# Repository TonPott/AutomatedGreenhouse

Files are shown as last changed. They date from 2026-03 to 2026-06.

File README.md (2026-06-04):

# Grow Controller (Arduino Nano 33 IoT)

This repository contains the firmware and project documentation for a grow controller based on an **Arduino Nano 33 IoT**.

The controller manages and monitors:

- temperature and humidity via an **SHT3x**
- a **12V 3-pin fan** with tachometer evaluation
- a **dimmable grow light** via AD5263 dimmer + relay
- a **capacitive soil moisture sensor**
- a **CQRTSL25911 / TSL25911 cabinet light sensor**
- a **DS3231 RTC with AT24C32 EEPROM**
- **Home Assistant** integration via **MQTT** using **ArduinoHA**

The system should work with Home Assistant and also continue operating locally and autonomously if the connection is lost.

## Project Structure

```text
.
|-- AGENTS.md
|-- README.md
|-- SPEC.md
|-- MODULES.md
|-- HARDWARE.md
|-- ROADMAP.md
|-- DECISIONS.md
|-- libraries.txt
|-- arduino-cli.yaml
|-- sketches/
|   `-- Smaeenhouse/
|       |-- Smaeenhouse.ino
|       |-- sketch.yaml
|       |-- Credentials.example.h
|       `-- *.h / *.cpp
|-- hardware-tests/
|   |-- README.md
|   `-- <test-sketch>/
|-- scripts/
|   |-- setup-arduino.*
|   |-- check-arduino.*
|   |-- cleanup-worktree.*
|   `-- cleanup-arduino-toolchain.*
`-- .github/workflows/arduino-compile.yml
```

The project remains Arduino-IDE-compatible. Open `sketches/Smaeenhouse/Smaeenhouse.ino` in the Arduino IDE.

## Project Overview For New Users

Recommended reading order:

1. Review the **schematic in the project folder** (`FullArduinoHouse.fzz`)
2. Read `SPEC.md` for functional requirements
3. Read `HARDWARE.md` for board, wiring, signal levels, and safety notes
4. Read `MODULES.md` for technical structure
5. Read `docs/entity-model.md` for Home Assistant entities
6. Read `ROADMAP.md` for open validation and follow-up work
7. Read `DECISIONS.md` for design rationale and major decisions
8. Read `libraries.txt` for required Arduino libraries

The schematic in the project folder is the primary wiring reference. Text documentation adds explanatory context for review and maintenance.

## Setup

Arduino CLI setup is a one-time preparation per local machine. The setup scripts may update Arduino indexes, install the board core, and prepare libraries.

Windows:

```powershell
.\scripts\setup-arduino.ps1
```

Linux / Codex Cloud / GitHub Actions:

```bash
./scripts/setup-arduino.sh
```

By default, all worktrees of this repository use a shared Arduino home:

- Windows: `%LOCALAPPDATA%\ArduinoCodex\<repo-name>\arduino-cli`
- Linux/macOS: `$HOME/.cache/arduino-codex/<repo-name>/arduino-cli`

Set `ARDUINO_PROJECT_HOME` to use a different toolchain location.

## Compile Check

Compile checks do not install anything. They generate an ignored local Arduino CLI configuration under `.local/arduino-cli.yaml`, use the shared toolchain, and write build output to `.build/`.

Windows:

```powershell
.\scripts\check-arduino.ps1
```

Linux / Codex Cloud / GitHub Actions:

```bash
./scripts/check-arduino.sh
```

The default sketch is `sketches/Smaeenhouse`. The default profile is `nano33iot`.

Hardware test example:

```powershell
$env:SKETCH = "hardware-tests/AD5263Test"
.\scripts\check-arduino.ps1
```

```bash
SKETCH=hardware-tests/AD5263Test ./scripts/check-arduino.sh
```

If the compile check reports that the Arduino toolchain is not prepared, run the matching setup script once and retry.

## Version Policy

This project pins core and library versions deliberately because the production firmware depends on specific board, networking, RTC, sensor, persistence, and Home Assistant APIs.

Keep these files in sync whenever dependencies change:

- `libraries.txt`
- `sketches/Smaeenhouse/sketch.yaml`
- `scripts/setup-arduino.ps1`
- `scripts/setup-arduino.sh`

Normal compile checks must not install missing dependencies. Run setup first when a pinned core or library version changes, then run the compile check.

## Credentials

Create a local `sketches/Smaeenhouse/Credentials.h` file based on `sketches/Smaeenhouse/Credentials.example.h`.

**Important:** `Credentials.h` must not be committed to the repository. The check scripts temporarily copy `Credentials.example.h` only when no real credentials file exists, and remove that temporary file after compilation.

For hardware-test compile checks that include credential-dependent modules, the scripts may temporarily copy the production example credentials into the selected test sketch folder. Real hardware uploads should use real local credentials, never committed credentials.

## Cleanup

Worktree-local generated files can be removed with:

```powershell
.\scripts\cleanup-worktree.ps1
```

```bash
./scripts/cleanup-worktree.sh
```

These scripts remove `.build/`, `.arduino-cache/`, `.local/`, and `.arduino/` in the current worktree. They do not delete the shared Arduino toolchain.

The shared toolchain is intentionally long-lived. Manual project-end cleanup uses separate scripts that require confirmation:

```powershell
.\scripts\cleanup-arduino-toolchain.ps1
```

```bash
./scripts/cleanup-arduino-toolchain.sh
```

## Important Hardware Notes

- The RTC module provides a **DS3231** RTC and **AT24C32** EEPROM. The firmware uses RTClib for the RTC and JC_EEPROM for the external EEPROM.
- The grow light is dimmed through an `AD5263BRUZ50` as a digitally adjustable resistance between `Dim+` and `Dim-`; the relay remains responsible for hard switching the mains supply.
- The fan tach signal is converted to 3.3 V logic through a **2N3904 transistor stage**. See `HARDWARE.md` for the exact signal-conditioning notes.
- The **SQW/INT output** of the DS3231 is used for Arduino-internal light schedule alarms.
- The CQRTSL25911 light sensor is placed inside the cabinet and is initially measurement-only. Its INT line is wired for future use, but the firmware polls it over I2C.

## Measurement Data Privacy

Real sensor histories and HA exports from the cabinet or room are sensitive project data. Keep timestamped measurements, calibration datasets, and analysis exports in ignored local folders such as `measurements/`, `data/`, `exports/`, `ha-history/`, or `home-assistant-history/`; do not commit them to GitHub.

## Home Assistant

The MQTT/HA integration is based on the Arduino Home Assistant Integration by Dawid Chyrzynski:

https://github.com/dawidchyrzynski/arduino-home-assistant

Further details are documented in `docs/entity-model.md`.

## Codex Workflow

- Open the repository root in the Codex app, not the sketch folder.
- Keep changes small and reviewable.
- After code or build configuration changes, run `scripts/check-arduino`.
- After documentation-only changes, a diff review is sufficient.
- Do not commit generated build artifacts.
- Run hardware tests and uploads to real boards locally.

Recommended local Codex actions:

```text
Arduino Setup   -> .\scripts\setup-arduino.ps1
Arduino Compile -> .\scripts\check-arduino.ps1
```

Current open tasks and validation steps are tracked in `ROADMAP.md`. Important design decisions are recorded in `DECISIONS.md`.

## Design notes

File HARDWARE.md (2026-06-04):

# HARDWARE.md - Physical Build And Wiring Overview

## Purpose

Document the physical hardware target for this firmware.

Keep wiring, pin assignments, power domains, and signal-level assumptions here so firmware changes can be reviewed against the real build. The schematic in the project folder (`FullArduinoHouse.fzz`) is the primary wiring reference.

## Target Board

- Board: Arduino Nano 33 IoT
- FQBN: `arduino:samd:nano_33_iot`
- Logic voltage: 3.3 V
- Firmware sketch: `sketches/Smaeenhouse/Smaeenhouse.ino`

## Connected Hardware

- CQrobot CQRSHT31FA temperature and humidity sensor (Sensirion SHT31-DIS-F, I2C + alert pin)
- 3-pin 12 V PC fan
- WINGONEER Tiny DS3231 AT24C32 I2C module
  - DS3231 RTC
  - AT24C32 external EEPROM
  - SQW/INT output for RTC alarms
- DFRobot Capacitive Soil Moisture Sensor SEN0308
- ViparSpectra P1000 grow light
  - 230 V supply switched via 3.3 V relay module
  - dimming through variable resistance between `Dim+` and `Dim-`
- AD5263BRUZ50 on TSSOP-24 adapter as digitally controlled resistance
- CQrobot CQRTSL25911 illuminance sensor (TSL25911, I2C + prepared interrupt line)
- Home Assistant with MQTT

## Power Domains

- USB / logic power: Arduino Nano 33 IoT 3.3 V logic domain.
- External actuator power: 12 V fan supply and relay-switched grow-light mains supply.
- Common ground requirements: low-voltage control/sensor circuitry must share the required reference ground according to the schematic.
- Mains wiring is outside firmware safety guarantees and must be built, isolated, fused, and enclosed safely.

## Pin Map

| Pin | Direction | Function | Notes |
|---|---|---|---|
| `7` | Input interrupt | SHT alert | ISR only sets `shtAlertPending`; I2C evaluation happens in loop code. |
| `10` | Input interrupt | DS3231 SQW/INT | ISR only sets `rtcAlarmPending`; RTClib alarm evaluation happens in loop code. |
| `2` | Output | Fan switch | Controls the 12 V fan switch stage. |
| `A1` | Input interrupt | Fan tach | 2N3904-conditioned inverted tach signal. |
| `3` | Output | Light power relay | Hard power switching for the grow light. |
| `4` | Output | AD5263 `SHDN` | External 10 kOhm pull-down; no internal pull-up. |
| `A0` | Analog input | Soil moisture | SEN0308 analog signal. |
| `9` | Input | CQRTSL25911 INT | Reserved and wired for future light-sensor interrupt use; firmware v1 polls over I2C and does not attach an ISR. |
| `SDA/SCL` | I2C | SHT31, DS3231, AT24C32, AD5263, CQRTSL25911 | Use 3.3 V-compatible pull-ups. |

## I2C Devices

| Device | Role | Address / Notes |
|---|---|---|
| SHT31-DIS-F | Temperature/humidity measurement and alert status | Address according to sensor wiring. |
| DS3231 | RTC and light schedule alarms | SQW/INT connected to `PIN_RTC_ALARM`. |
| AT24C32 | External EEPROM for persistent configuration | Fixed project address `0x57`. |
| AD5263BRUZ50 | Grow-light dimmer resistance path | Fixed project address `0x2C` (`AD0 = GND`, `AD1 = GND`). |
| CQRTSL25911 / TSL25911 | Cabinet illuminance measurement | Fixed sensor address `0x29`; INT line is wired to `PIN_LIGHT_SENSOR_INT` for future use. |

No I2C access may happen in ISRs.

## Cabinet Light Sensor Placement

The CQRTSL25911 is placed inside the plant cabinet, where it measures the light that actually reaches the cabinet environment. Because the sensor is under the grow light when the lamp is on, it is not a reliable standalone room ambient-light sensor during lamp operation.

In the initial firmware integration, this sensor is measurement-only:

- cabinet illuminance and raw light channels are published to Home Assistant
- the light schedule, dimming jobs, and fallback behavior are not changed by the sensor
- the INT line is physically prepared, but no interrupt-driven light-sensor logic is used yet

## Light Dimmer Signal Conditioning

The grow light is dimmed through an `AD5263BRUZ50` as a digitally adjustable resistance between `Dim+` and `Dim-`.

Hardware assumptions:

- AD5263BRUZ50 in I2C mode (`DIS = 1`)
- pull-ups on SDA/SCL to 3.3 V
- `SHDN` on `PIN_LIGHT_DIM_SHDN` with external 10 kOhm pull-down
- no internal pull-up on `SHDN`
- analog channel wiring: `Dim+ -> W2 -> B2 -> A1 -> W1 -> Dim-`
- minimal effective resistance / approximately 0 Ohm = 0 %
- maximal effective resistance / approximately 100 kOhm = 100 %

Reference mapping:

- `0 %  => W2 = 0,   W1 = 255`
- `50 % => W2 = 0,   W1 = 0`
- `100 % => W2 = 255, W1 = 0`

The relay remains responsible for hard switching the 230 V supply.

## Fan Tach Signal Conditioning

The fan tach signal is converted to 3.3 V logic for the Nano 33 IoT through a **2N3904 transistor stage**:

- fan tach with 10 kOhm pull-up to 9 V
- tach through 47 kOhm to the base of a 2N3904
- 100 kOhm from base to GND
- emitter to GND
- collector to `PIN_FAN_TACH`
- 10 kOhm pull-up from collector to 3.3 V

The resulting signal is inverted; firmware must select the interrupt edge accordingly.

## Safety Notes

- Do not rely on firmware as the only safety layer for mains wiring.
- Relay wiring, mains isolation, strain relief, fuse protection, and enclosure design must be handled physically.
- Keep water, soil, condensation, and low-voltage electronics physically separated from mains wiring.
- The AD5263 dimmer path is not galvanically isolated by firmware.
- Hardware tests that actuate the relay or light require a safe physical setup.

## Open Hardware Validation Items

Track concrete validation work in `ROADMAP.md`; keep only hardware context here.

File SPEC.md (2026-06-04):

## Requirements List

## 1. Project Goal

The Arduino Nano 33 IoT controls a grow setup with:

- SHT3x temperature/humidity sensor
- 12V fan with tachometer signal
- dimmable grow light
- RTC_DS3231 + external AT24C32 EEPROM
- capacitive soil moisture sensor
- Home Assistant integration via MQTT

The system should cooperate with Home Assistant, but continue operating locally and autonomously if the connection is lost.

## 2. Hardware

### 2.1 Microcontroller
- Arduino Nano 33 IoT

### 2.2 Sensors And Actuators
- SHT3x via I²C with alert pin
- 3-pin 12V PC fan
- WINGONEER Tiny DS3231 AT24C32 I2C module
  - RTC via I²C with RTClib, type `RTC_DS3231`
  - external I²C EEPROM `AT24C32`
  - SQW/INT output for RTC alarms
- Grow Light:
  - dimming via a digitally adjustable resistance (AD5263) between `Dim+` and `Dim-`
  - hard shutoff via 3.3 V relay module
- DFRobot Capacitive Soil Moisture Sensor SEN0308
- WiFi + MQTT to Home Assistant

### 2.3 Hardware Documentation Requirement
The project documentation should also be understandable for users seeing the project for the first time.
The schematic in the project folder is the primary reference and should be explicitly mentioned in the text documents.

## 3. Pin Assignment

- SHT Alert: Pin 7
- RTC Alarm (SQW/INT): Pin 10
- Fan Switch: Pin 2
- Fan Tach: Pin A1
- Light Power Relay: Pin 3
- Light Dim SHDN: Pin 4
- Light Dimmer: I²C (SDA/SCL, AD5263 @ 0x2C)
- Soil Moisture: Pin A0

## 4. Temperature / Humidity / SHT3x
### 4.1 Measurement
The SHT3x periodically measures temperature and humidity.

These values should be:
- usable locally
- transmitted to Home Assistant

### 4.2 Thresholds
There are configurable thresholds:

- `TEMP_HIGH_SET`
- `TEMP_HIGH_CLEAR`
- `TEMP_LOW_SET`
- `TEMP_LOW_CLEAR`
- `HUM_HIGH_SET`
- `HUM_HIGH_CLEAR`
- `HUM_LOW_SET`
- `HUM_LOW_CLEAR`

These values should be:
- stored persistently in the external EEPROM
- written to the sensor at startup
- changeable from HA

### 4.3 Interrupt Logic
The SHT3x performs threshold monitoring.

When an alert occurs on pin 7, the status register is decoded. The relevant bits are especially:

- `alertTriggers[2]` = humidity tracking alert
- `alertTriggers[3]` = temperature tracking alert
- `alertTriggers[4]` = sensor reset detected

### 4.4 Reinitialization After Sensor Reset
If `alertTriggers[4]` is set, this should be used to reinitialize the sensor, or at least to write the configured thresholds to the sensor again.

### 4.5 Responsibility
- The FanController evaluates **no thresholds of its own**
- The SHT3x alert logic is authoritative

## 5. Fan

### 5.1 Automatic Mode
The fan is controlled based on the SHT3x alert logic:

- relevant alerts active → fan on
- clear state reached → fan off

### 5.2 Manual Mode
The fan should be manually switchable on and off in HA.

### 5.3 Auto Mode
There is an auto-mode switch for the fan:

- ON: sensor interrupts control the fan
- OFF: sensor interrupts are ignored, manual control remains active

### 5.4 RPM
The fan has 2 pulses per revolution.

RPM:
- measurement window 30 seconds
- only measure/publish if the fan should be running

### 5.5 Hardware Signal Conditioning For Tachometer
The documentation should include the used 2N3904 stage:

- tach line with 10 kΩ pull-up to 9 V
- tach through 47 kΩ to the base of a 2N3904
- 100 kΩ from base to GND
- emitter to GND
- collector to Arduino `PIN_FAN_TACH`
- 10 kΩ pull-up from collector to 3.3 V

The resulting signal is inverted.

## 6. Grow Light

### 6.1 Basic Structure
The light has two separate control paths:

- AD5263 dimmer path as variable resistance between `Dim+` and `Dim-`
- hard relay-off of the 230 V supply

### 6.2 Mandatory AD5263 Hardware

- Component: `AD5263BRUZ50`
- Mounted via TSSOP-24 adapter
- Supply:
  - `VDD = 12 V`
  - `VSS = GND`
  - `VL/VLOGIC = 3.3 V`
- Decoupling:
  - `100 nF` or `1 µF` between `VDD` and `VSS`
  - `100 nF` between `VL` and `GND`
- no galvanic isolation in the dimmer path

### 6.3 I²C Mode And Address

- `DIS = 1` for I²C mode
- `SDI/SDA` = SDA
- `CLK/SCL` = SCL
- `CS/AD0` and `RES/AD1` are the I²C address bits
- `AD0 = GND`
- `AD1 = GND`
- fixed 7-bit I²C address: `0x2C`
- pull-ups on the I²C lines to `3.3 V`

### 6.4 Mandatory Analog Channel Wiring

Only channel 1 and channel 2 of the AD5263 are used.

Mandatory signal path:

- `Dim+ -> W2 -> B2 -> A1 -> W1 -> Dim-`

### 6.5 Brightness Mapping To RDAC Values

The firmware continues to work logically with `0..100 %` brightness and maps internally to RDAC values.

Functional direction at the lamp dimmer input:

- low resistance between `Dim+` and `Dim-` = low brightness
- high resistance between `Dim+` and `Dim-` = high brightness
- minimal effective resistance / approximately `0 Ω` corresponds to `0 %`
- maximal effective resistance / approximately `100 kΩ` corresponds to `100 %`

Mandatory points:

- `0 % = W2 0, W1 255`
- `50 % = W2 0, W1 0`
- `100 % = W2 255, W1 0`

Mandatory intermediate logic:

- from `0 %` to `50 %`, channel 1 / `W1` changes first so the total resistance rises from the minimum value to the midpoint
- from `50 %` to `100 %`, channel 2 / `W2` changes afterwards so the total resistance rises from the midpoint to the maximum value
- on channel 1 the `A1-W1` stretch is used
- on channel 2 the `W2-B2` stretch is used

### 6.6 Resistance Limits

- target range at the light input: nominally approx. `0..100 kΩ`
- `0 Ω` is to be understood as minimal effective resistance or approximately `0 Ω`, because the AD5263 has residual resistance in rheostat mode
- practically approximated by the AD5263BRUZ50 with two channels in rheostat mode
- actually used lower/upper limits are set as project-internal firmware constants
- these dimmer limits are **not** configurable via HA

### 6.7 Two Control Worlds
A clean distinction must be maintained between:

- **Arduino Auto Schedule**
- **HA-controlled operation** (manual or by HA schedule)

The two must not control the light at the same time.

### 6.8 Light Modes

#### Mode A: Arduino Auto Mode ON
When `light_auto_mode = ON`:

- the internal Arduino schedule is active
- triggers from the HA schedule are ignored
- manual brightness adjustment is allowed, but only temporarily within the current time window
- at the next Arduino schedule event, the value is overwritten again
- the HA on/off switch for the light should have no effect in this mode or should be disabled

#### Mode B: Arduino Auto Mode OFF
When `light_auto_mode = OFF`:

- the Arduino schedule is inactive
- HA schedule triggers may control the light
- manual HA commands may control the light like a normal dimmable light
- on/off switch and brightness slider are active

### 6.9 Dimming Behavior
There is **no longer a single global fixed dimming ramp for all cases**.

Instead:

- Arduino schedule fades use the configured auto dim duration
- HA schedule commands use the duration provided by the command
- purely manual slider/switch operation in HA mode may make the light react immediately like a normal dimmable light

### 6.10 Hard Power Off
There is an additional separate HA switch/command for hard power off.

`light_hard_power_off` is an always-available safety override and may act in both Arduino Auto Mode and HA-controlled mode. It should not be hidden in the associated light/control cards based on light mode.

It should:

- switch only the relay immediately
- keep the internal dimmer state

### 6.11 SHDN Usage

- `SHDN` is actively used and pin 4 is used for it
- an external `10 kΩ` pull-down to GND is mandatory on `SHDN`
- because of this external pull-down, no internal pull-up is used for `SHDN`
- the AD5263 should remain in shutdown by default during reset/boot

### 6.12 Startup And Shutdown Sequence

Important:

- the AD5263 starts at midscale on power-on
- without a sequence, switching the relay on would otherwise cause an incorrect brightness start

Mandatory startup sequence:

1. AD5263 initially remains in `SHDN` during boot
2. Load configuration
3. Reconstruct target state
4. Set resistance value
5. Release `SHDN`
6. Only then close the relay

Mandatory shutdown sequence:

1. Open relay
2. Then put AD5263 into `SHDN`

### 6.13 Race Condition And Logic Rules For The Light
1. There is always exactly **one active light control source**:
   - Arduino Auto
   - or HA

2. When `light_auto_mode = ON`, HA schedule triggers are ignored.

3. When `light_auto_mode = OFF`, Arduino schedule events are ignored.

4. A new valid dimming request replaces any still-running old dimming request from the active control source.

5. When switching modes, a running dimming request is terminated; the new control source takes over only with its next valid command/event.

### 6.14 Fault Strategy For The Light Path

The AD5263 must be reachable before the relay is switched on and must provide a plausibly set target resistance. In case of AD5263 communication, write, or plausibility errors, the relay remains or is opened, the light stays off, and `light_fault` is set.

The technical retry/readback strategy belongs to the module description in `MODULES.md`.

Intended text values for `light_fault_reason`:

- `ad5263_not_found`
- `ad5263_write_failed`
- `ad5263_readback_mismatch`

## 7. Light Schedule Via DS3231 Alarms
### 7.1 Arduino-Internal Schedule
The Arduino stores internally:

- on / dim-on time
- off / dim-off time
- default dim duration

### 7.2 Time Format
Internal:
- minutes since midnight

### 7.3 RTC Alarm Usage
The Arduino-internal schedule should be implemented using the **two alarm registers of the DS3231**.

Requirements:
- the stored on/off times are written to the DS3231 alarm registers
- when an alarm occurs, an interrupt is triggered through the `SQW/INT` pin
- the ISR only sets a flag
- the main loop evaluates which alarm fired
- then the corresponding on/off dimming request is started

### 7.4 Library Requirement
It must be checked and used in the implementation that RTClib provides the required functions for `RTC_DS3231`, especially:

- `writeSqwPinMode(...)`
- `setAlarm1(...)`
- `setAlarm2(...)`
- `alarmFired(...)`
- `clearAlarm(...)`

### 7.5 Pull-Up Of The Alarm Line
Because `SQW/INT` is open drain, at least `INPUT_PULLUP` should be used on the Arduino side.
If the real line is unstable, an additional external pull-up to 3.3 V may be provided.

### 7.6 Distinction From HA Schedule
Section 7 applies only to the **Arduino-internal schedule**.

An additional HA schedule is separate from it and only effective when `light_auto_mode = OFF`.

## 8. Soil Moisture

### 8.1 Measurements
The following should be available:
- `sensor.soil_moisture_percent`: calculated soil moisture in %
- `sensor.soil_moisture_raw`: raw sensor value

### 8.2 Calibration Parameters
- `number.soil_air`
- `number.soil_water`
- `number.soil_depth_mm`

These values:
- are stored persistently
- are shown in HA
- can be changed in HA

`soil_air` and `soil_water` remain user-facing persistence values in the expected project range:

- min: 0
- max: 1000
- step: 1

Separately, the firmware sensor module may defensively clamp internal ADC raw values to the 12-bit safety range `0..4095`.

`soil_depth_mm` is an active correction parameter for percent calculation, not only an informational value.

### 8.3 Calibration
The calibration routine runs fully in HA.
The firmware does not manage a calibration assistant and does not contain an internal calibration state machine.

Therefore the firmware does not need to:
- know the calibration step
- pause measurements
- maintain an internal calibration status
- store individual intermediate steps

The firmware only needs to:
- periodically read the raw value
- periodically calculate the percent value from `soil_air`, `soil_water`, current raw value, and `soil_depth_mm`
- publish `sensor.soil_moisture_raw`
- publish `sensor.soil_moisture_percent` if the evaluation is valid
- provide the raw value on request
- accept final changes to `number.soil_air`, `number.soil_water`, and `number.soil_depth_mm`
- store changed persistence values in the external EEPROM

### 8.4 HA Operation
One firmware button is sufficient:

- `button.read_soil_raw_value`

Separate firmware buttons such as `capture_soil_air` or `capture_soil_water` should not be introduced. The existing generic button plus HA scripts/automations is sufficient and avoids unnecessary MQTT entities.

Intended HA-supported workflow:

1. Air step:
   - The user places the sensor dry in air.
   - HA calls `button.read_soil_raw_value`.
   - HA waits briefly until `sensor.soil_moisture_raw` is updated.
   - HA writes this value to `number.soil_air`.

2. Water step:
   - The user places the sensor in water at the reference depth of `120 mm`.
   - HA calls `button.read_soil_raw_value`.
   - HA waits briefly until `sensor.soil_moisture_raw` is updated.
   - HA writes this value to `number.soil_water`.

3. Depth step:
   - The user manually enters the actual insertion depth in the substrate in `number.soil_depth_mm`.
   - The firmware actively uses this value for the corrected percent calculation.

### 8.5 Depth Correction And Percent Calculation
The sensor response depends on how much active sensor area is actually inside the medium. Therefore the firmware uses a simple linear depth correction.

Definitions:

- `SOIL_REFERENCE_DEPTH_MM = 120`
- `soil_air`: raw value with sensor completely in air
- `soil_water`: raw value with sensor in water at 120 mm reference depth
- `soil_depth_mm`: actual insertion depth in the substrate

Concept:

```text
depth_factor = soil_depth_mm / SOIL_REFERENCE_DEPTH_MM
percent = (soil_air - raw) / ((soil_air - soil_water) * depth_factor) * 100
```

The air reference corresponds to `0 %`, and the water reference at `120 mm` corresponds to `100 %`. Valid results are constrained to `0..100 %`. The formula is a deliberate linear approximation; a measurement series exists, but the project currently accepts this model as sufficiently accurate.

### 8.6 Invalid Depth
Values below `20 mm` are considered invalid for soil moisture percent calculation.

Reason:

- The first physical sensor marking is at `20 mm`.
- Measurements below that are considered unreliable.

Constant meanings:

- `SOIL_DEPTH_MIN_MM = 0` is the technical/persistence lower bound and defensive lower bound for stored or injected values.
- `SOIL_MIN_VALID_DEPTH_MM = 20` is the first physical sensor marking, the minimum meaningful insertion depth, and the normal Home Assistant UI minimum.

Home Assistant normally exposes `number.soil_depth_mm` as `20..120 mm`. Values below `20 mm` are a defensive invalid state, not a normal user input path.

Firmware behavior:

- If `soil_depth_mm < 20`, `sensor.soil_moisture_percent` should be treated as invalid or unavailable.
- `sensor.soil_moisture_raw` may still be published.
- In this case, the firmware should not produce a misleading corrected percent value.

### 8.7 Measurement Interval
The soil moisture sensor should be read:
- every **10 seconds**
- and published to HA

It is useful to publish both:
- the raw value
- and the calculated percent value

## 9. RTC / Time / EEPROM

### 9.1 RTC Type
- `RTC_DS3231`

### 9.2 External EEPROM
Persistent configuration should not be stored in Arduino flash, but in the **AT24C32** on the RTC module.
Access to this EEPROM is performed through the **JC_EEPROM** library (which requires the **Streaming** library).
The I²C address of the AT24C32 EEPROM on the WINGONEER Tiny DS3231 AT24C32 I2C module has been verified in the real build and is fixed for this project.
It is 0x57.

Requirements:
- The firmware should use this known EEPROM I²C address directly.
- The EEPROM address should not be guessed, scanned, or searched automatically at runtime.
- The address is defined centrally in `Config.h` or a comparable configuration file.
- The persistence layer uses this fixed address for all read/write access through `JC_EEPROM`.
- The **JC_EEPROM** library requires the **Streaming** library as a dependency.

Reason:
- The EEPROM was accessed successfully with `JC_EEPROM` in the test build.
- This removes unnecessary auto-detection and keeps initialization simpler and more robust.

### 9.3 Usage
The RTC is the local time base for:
- Arduino light schedule
- autonomous operation when the connection is lost

The RTC alarms are the trigger source for the Arduino-internal light schedule.

### 9.4 Synchronization
The time should be synchronized:
- during boot
- at least 1× per day afterwards

Optionally additionally:
- manual sync via HA button

### 9.5 NTP
The firmware should actively synchronize via NTP and set the RTC from it.

Default NTP server:

- `pool.ntp.org`

NTP diagnostics should distinguish these failure classes in serial logs:

- DNS lookup failure
- UDP socket setup failure
- UDP packet send failure
- missing UDP response
- short UDP response
- invalid NTP timestamp

After an explicit UDP NTP failure, the firmware may use `WiFi.getTime()` as a secondary WiFiNINA module-time fallback/check. This fallback must not add HA entities.

UDP NTP sync may block briefly while waiting for a response during boot, manual sync, or daily resync. This is acceptable for now because it happens only during those sync attempts.

After successful time sync, the DS3231 alarm registers should be rewritten.

## 10. Cabinet Light Sensor

### 10.1 Sensor Type
The firmware includes a CQrobot CQRTSL25911 / TSL25911 light sensor on I2C address `0x29`.

The sensor is mounted inside the plant cabinet. It measures the cabinet light environment, not a clean room ambient-light value while the grow light is on.

### 10.2 Initial Firmware Role
The initial integration is measurement-only:

- read the sensor from normal loop code only
- publish cabinet illuminance and raw light-channel values to HA
- publish a separate `light_sensor_fault` state if repeated reads fail
- do not change the Arduino light schedule
- do not change HA dimming semantics
- do not change fallback or standalone light behavior

The sensor INT pin is wired to `PIN_LIGHT_SENSOR_INT` for future use. Firmware v1 does not attach an ISR and does not read I2C from interrupt context.

### 10.3 Future Lux-Hour Assistance
Future light assistance may use Home Assistant history to combine:

- cabinet illuminance from this sensor
- outside brightness from the existing exterior HA sensor
- current `grow_light` brightness
- time of day and schedule window

The intended future direction is a gradual lux-hour or light-sum compensation model. It should avoid end-of-day catch-up behavior where the lamp suddenly switches to full power because the daily total is low. Instead, HA should derive expected brightness by time of day and apply slow corrections through the existing HA dimming entities while `light_auto_mode = OFF`.

Standalone and fallback behavior remains conservative until a separate design explicitly defines safe local lux-based corrections. By default, connection loss continues to use the existing fallback behavior without lux-hour compensation.

### 10.4 Measurement Data Sensitivity
Real measurement histories are sensitive project data. Home Assistant exports, timestamped lux histories, calibration tables, and analysis datasets from the real cabinet or room must remain local and must not be committed to GitHub.

Documentation may describe algorithms and may include synthetic or anonymized examples, but not raw real-world measurement histories.

## 11. Home Assistant / MQTT

### 11.1 Library
Used library:
- Arduino Home Assistant Integration by Dawid Chyrzynski
- Reference: `https://github.com/dawidchyrzynski/arduino-home-assistant`

### 11.2 Device
The Arduino appears as one HA device.

### 11.3 HA Entities

#### Sensors
- `temperature`
- `humidity`
- `soil_moisture_percent`
- `soil_moisture_raw`
- `cabinet_illuminance_lux`
- `cabinet_light_full_spectrum_raw`
- `cabinet_light_infrared_raw`
- `cabinet_light_visible_raw`
- `fan_rpm`
- `light_fault`
- `fan_fault`
- `sht_fault`
- `rtc_fault`
- `eeprom_fault`
- `light_sensor_fault`
- `light_fault_reason`

Type mapping in HA:

- `binary_sensor.light_fault`
- `binary_sensor.fan_fault`
- `binary_sensor.sht_fault`
- `binary_sensor.rtc_fault`
- `binary_sensor.eeprom_fault`
- `binary_sensor.light_sensor_fault`
- `sensor.light_fault_reason` (text)

#### Switches
- `fan`
- `fan_auto_mode`
- `light_auto_mode`
- `light_hard_power_off`
- `light_fallback_to_auto`

#### Light
- `grow_light`
  - Brightness
  - ON/OFF
  - fully usable only when `light_auto_mode = OFF`

#### Number Entities
- temperature thresholds
- humidity thresholds
- Arduino light schedule times
- Arduino default dim duration
- `soil_air`
- `soil_water`
- `soil_depth_mm`
- `ha_dim_target_percent`
- `ha_dim_duration_minutes`

#### Buttons
- `sync time`
- `read_soil_raw_value`
- `start_ha_dim`

### 11.4 HA Dimming Request
For the HA schedule dimming job, operation is fixed as follows:

- `number.ha_dim_target_percent`
- `number.ha_dim_duration_minutes`
- `button.start_ha_dim`

Mandatory behavior:

- These three entities are used only for **HA schedule operation**
- They are effective only when `light_auto_mode = OFF`
- Pressing `button.start_ha_dim` starts a dimming request on the Arduino:
  - from the **current actual state**
  - to `ha_dim_target_percent`
  - within `ha_dim_duration_minutes`
- If `light_auto_mode = ON`, this dimming request is ignored

Persistence rule:

- The Number entities remain runtime/command parameters and are not durable configuration.
- If a HA dimming job is relevant after restart, its resumption is reconstructed through the `Light Resume State` (start/target/duration/start time on RTC/Epoch basis), not through `millis()`.

### 11.5 State Restoration
Separate sensors for actual light brightness or light mode are not required as long as:

- the state of the `light` entity is published correctly
- the `switch` states are published correctly
- after startup or MQTT reconnect, the current states are actively reported to HA again

## 12. Network / Connection Behavior

### 12.1 Connection
The device connects to:
- WiFi
- MQTT broker

### 12.2 Credentials
All credentials are in local `sketches/Smaeenhouse/Credentials.h`, at least:
- WiFi SSID
- WiFi password
- MQTT Host
- MQTT Port
- MQTT User
- MQTT password
- Device Name / ID / Prefix
- NTP server
- timezone / offset if needed

### 12.3 Availability / LWT
The device reports availability via MQTT and uses LWT.

### 12.4 Reconnect
On WiFi/MQTT outage, reconnect is automatic.

WiFi reconnect behavior must account for stale WiFiNINA connection state after sketch upload or module state transitions:

- force a WiFi disconnect before a reconnect sequence
- wait a short settle interval after disconnect
- use a bounded number of connection attempts
- use a connect timeout for each attempt
- keep diagnostics compact enough for serial troubleshooting

MQTT reconnect must be retried periodically while WiFi is connected. It must not depend only on a WiFi state transition.

### 12.5 Fallback After Connection Loss
If the connection is not restored for more than 10 minutes, a configurable behavior should apply for the light:

- turn light off
- or switch to internal Arduino Auto Mode

This behavior should be configurable via HA.

Other local functions such as sensors, RTC, EEPROM, and fan logic continue running.

## 13. Persistence

### 13.1 Storage Location
Used storage:

- `AT24C32` on the RTC module
- access through **JC_EEPROM**

### 13.2 Already Existing Persistent Configuration (Reuse)
Already existing and **not** to be created a second time:

- `lightAutoMode`
- `fanAutoMode`
- `lightOnTimeMinutes`
- `lightOffTimeMinutes`
- `defaultLightDimMinutes`
- `lightFallbackMode`
- additional sensor/soil/threshold values

### 13.3 Light Resume State (Add New)
In addition, a small resume state is required for target-state reconstruction, at least with:

- last effective brightness
- `hardPowerOffActive`
- flag whether a HA dimming job was active
- start brightness
- target brightness
- job duration
- job start time on RTC/Epoch basis

### 13.4 Time Base For Resumption

- `millis()` is not sufficient for restart resumption.
- Correct reconstruction after restart requires an RTC/Epoch-based time reference.

### 13.5 Write Behavior

- Write only when values actually changed.
- Design resume-state writes so unnecessary EEPROM load is avoided.

## 14. Architecture
### 14.1 Non-Blocking
- no long `delay()` calls
- control via `millis()`
- short I²C waits are allowed

### 14.2 Module Boundaries
- SHTa: sensor + alert evaluation
- FanController: fan switching + RPM measurement
- LightController: AD5263/relay + dimming requests
- LightSensor: CQRTSL25911/TSL25911 cabinet illuminance measurement
- ClockService: DS3231 + alarm management + NTP sync
- HAInterface: HA entities + commands
- NetworkManager: WiFi/MQTT + reconnect
- Persistence: external EEPROM

### 14.3 Fault States (Mandatory)
The following fault states are mandatory in the firmware documentation:

- `light_fault`
- `fan_fault`
- `sht_fault`
- `rtc_fault`
- `eeprom_fault`
- `light_sensor_fault`

In HA, these fault flags are published as `binary_sensor`.

Do not use:

- `sensor_fault`
- `system_fault`
- `last_fault_code`

Additional text state:

- `light_fault_reason`

In HA, `light_fault_reason` is published as a text `sensor`.

Intended contents of `light_fault_reason`:

- `ad5263_not_found`
- `ad5263_write_failed`
- `ad5263_readback_mismatch`

Mandatory behavior rules:

- AD5263 not reachable during boot: relay open, light off, set `light_fault`, `light_fault_reason = ad5263_not_found`.
- AD5263 error during operation: open relay, set `light_fault`, update `light_fault_reason`.
- The concrete retry/readback strategy is documented in `MODULES.md`.
- Fan fault: if the fan should effectively be on but no tach pulses are present after the grace period, set `fan_fault`.
- Do not claim strong hardware self-diagnostics for relay and soil moisture sensor, because there is no real feedback channel.

## 15. Reused Existing Code
### 15.1 SHTa
The following should especially be reused:

- `begin()`
- `startPeriodicMeasurement()`
- `blockingReadMeasurement()`
- `decodeStatusRegister()`
- `clearStatus()`
- `writeHighLimit()`
- `writeHighClear()`
- `writeLowLimit()`
- `writeLowClear()`
- `readLimit()`
- `limitPrinter()`
- `crc8()`
- `encodeAlertLimit()`

### 15.2 Alert Structure
- `alertTriggers[]` remains as status container

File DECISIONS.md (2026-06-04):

# Design Decisions

This file records important design, hardware, and architecture decisions for the project.
It explains why the current design looks the way it does.
It does not replace `README.md`, `SPEC.md`, `MODULES.md`, or `ROADMAP.md`.

## 2026-05 – Cabinet light sensor starts as measurement-only

Status: accepted

### Context

- The CQRTSL25911 sensor can only be placed inside the plant cabinet.
- When the grow light is on, the sensor measures the combined cabinet light environment and cannot independently evaluate room ambient light.
- A future light-sum design should also consider the outside brightness sensor that already exists in Home Assistant.

### Decision

- Integrate the CQRTSL25911 / TSL25911 first as a measurement-only firmware module.
- Publish cabinet illuminance and raw light channels to Home Assistant.
- Keep the existing Arduino schedule, HA dimming interface, and fallback behavior unchanged.
- Prepare the sensor INT line physically, but use polling in the initial firmware.
- Treat real measurement histories and HA exports as sensitive local data that must not be committed.

### Consequences

- The sensor can be logged in HA before any automatic control logic is designed.
- Future lux-hour compensation should be HA-first and should use existing HA dimming entities while `light_auto_mode = OFF`.
- Standalone/fallback lux-based behavior remains future work and must be designed explicitly before implementation.

### Affected Areas

- `SPEC.md`
- `MODULES.md`
- `HARDWARE.md`
- `docs/entity-model.md`
- `sketches/Smaeenhouse/LightSensor.*`
- `sketches/Smaeenhouse/HAInterface.*`

## 2026-05 – AD5263 replaces the old PWM/RC/PC817 dimmer concept

Status: accepted

### Context

- The old PWM/RC/PC817 dimmer path is no longer the target design.
- The lamp is controlled through a resistance between `Dim+` and `Dim-`.
- A digital potentiometer approach better matches the required control interface.

### Decision

- Use `AD5263BRUZ50` as the target dimmer component.
- Use two channels in series.
- Keep the hard relay path separate for 230 V power switching.
- Use SHDN for safe startup/shutdown behavior.

### Consequences

- The firmware uses AD5263/I²C control instead of PWM dimming.
- The old PWM/RC/PC817 path must not be reintroduced as a runtime option.
- Fault handling must protect against AD5263 communication/readback failures.
- Documentation and code must remain aligned on the AD5263 mapping.

### Affected Areas

- `SPEC.md`
- `MODULES.md`
- `sketches/Smaeenhouse/Config.h`
- `sketches/Smaeenhouse/LightController.*`
- `hardware-tests/AD5263Test/AD5263Test.ino`

## 2026-05 – Lamp dimmer direction is low resistance = low brightness, high resistance = high brightness

Status: accepted

### Context

- Real hardware testing showed that the previous mapping direction was inverted for the lamp.
- Swapping `Dim+` and `Dim-` is not expected to change a pure resistance input.

### Decision

- Treat minimal effective resistance / approximately `0 Ω` as `0 %`.
- Treat maximal effective resistance / approximately `100 kΩ` as `100 %`.
- Use the mapping:
  - `0 %  => W2 = 0,   W1 = 255`
  - `50 % => W2 = 0,   W1 = 0`
  - `100 % => W2 = 255, W1 = 0`

### Consequences

- Code, documentation, and AD5263 test sketch must use this mapping.
- Future changes to dimmer limits must preserve the direction unless new hardware evidence says otherwise.

### Affected Areas

- `SPEC.md`
- `MODULES.md`
- `sketches/Smaeenhouse/Config.h`
- `sketches/Smaeenhouse/LightController.cpp`
- `hardware-tests/AD5263Test/AD5263Test.ino`

## 2026-05 – Project documentation is maintained in English

Status: accepted

### Context

- The project should be useful to more readers.
- Chats with the user may continue in German, but repository documentation should be accessible internationally.

### Decision

- Maintain repository documentation in English.
- Code, identifiers, comments, and commit summaries remain English.

### Consequences

- `AGENTS.md` must tell Codex to keep documentation and code in English.
- German chat context should be translated into clean English repository documentation when applied.

### Affected Areas

- all documentation files
- `AGENTS.md`

## 2026-05 – Main documentation describes the current target state, not development history

Status: accepted

### Context

- README, SPEC, MODULES, and entity model are easier to use if they describe the current target project.
- Open tasks and historical rationale made the main docs less clear.

### Decision

- Keep README/SPEC/MODULES/entity-model focused on the current target state.
- Move open tasks to `ROADMAP.md`.
- Move rationale and historical design decisions to `DECISIONS.md`.

### Consequences

- README should not contain a long roadmap/open-issues section.
- SPEC and MODULES should not include version history or discarded implementation paths unless needed to describe the current state.
- AGENTS may reference ROADMAP and DECISIONS but should not duplicate them heavily.

### Affected Areas

- `README.md`
- `SPEC.md`
- `MODULES.md`
- `docs/entity-model.md`
- `AGENTS.md`
- `ROADMAP.md`
- `DECISIONS.md`

## 2026-06 – Network diagnostics stay separate from production firmware

Status: accepted

### Context

- Real hardware testing showed that network failures can look like firmware faults when WiFi, DNS, MQTT, Home Assistant discovery, and NTP are tested only through the production sketch.
- After uploading a new sketch while an older network test is running, the Nano 33 IoT / WiFiNINA stack may keep an old connection state long enough for the first WiFi connection attempt to fail.
- Home Assistant MQTT discovery uses entity unique IDs for registry identity, so diagnostic entities must not reuse production unique IDs.
- `WiFi.getTime()` can be used as an independent WiFiNINA module time check alongside explicit UDP NTP requests.

### Decision

- Keep the network diagnostics sketch as a standalone hardware test, not as production runtime logic.
- Use test-local placeholder credentials and do not include production `Credentials.h`.
- Use diagnostic-specific device and entity identifiers.
- Prefer `pool.ntp.org` as the default external NTP server for firmware and diagnostics.
- Keep diagnostic HA entities out of production firmware.
- Implement production WiFi reconnect hardening, periodic MQTT reconnect, and richer NTP error reporting without changing production HA entity IDs.

### Consequences

- Network troubleshooting can separate WiFi/DNS/MQTT/HA/NTP behavior from sensors, actuators, RTC, EEPROM, and dimmer hardware.
- Production firmware remains focused, but now carries the connection hardening learned from the diagnostics sketch.
- Future HA diagnostic devices should avoid unique ID collisions with production entities.
- NTP troubleshooting can compare explicit UDP requests with the WiFiNINA module time source, and production serial logs now report the relevant failure class.
- Production UDP NTP sync may still block briefly while waiting for a response. This is accepted for now because sync attempts happen only at boot, manual sync, or daily resync; a non-blocking NTP state machine remains a future improvement.

### Affected Areas

- `hardware-tests/NetworkDiagnosticsTest/NetworkDiagnosticsTest.ino`
- `hardware-tests/NetworkDiagnosticsTest/README.md`

## 2026-06 – Dependency declarations remain duplicated for now

Status: accepted

### Context

- Arduino dependencies are currently listed in multiple places: `libraries.txt`, `sketches/Smaeenhouse/sketch.yaml`, setup scripts, and check scripts.
- The CQRTSL25911 / TSL25911 integration added Adafruit sensor dependencies and exposed the risk that setup and check script lists can drift apart.

### Decision

- Keep the current duplicated dependency declarations for this branch.
- Keep `libraries.txt` as human-readable dependency documentation.
- Update setup/check script library checks explicitly when dependencies change.

### Consequences

- Dependency handling remains simple and compatible with the current scripts.
- Future work should consider a single machine-readable dependency source that setup/check scripts can consume.

### Affected Areas

- `libraries.txt`
- `sketches/Smaeenhouse/sketch.yaml`
- `scripts/setup-arduino.ps1`
- `scripts/setup-arduino.sh`
- `scripts/check-arduino.ps1`
- `scripts/check-arduino.sh`
- `ROADMAP.md`

## 2026-05 – Soil moisture calibration is HA-guided and firmware remains stateless for calibration workflow

Status: accepted

### Context

- The firmware provides raw and calculated values.
- HA orchestrates the calibration workflow.

### Decision

- Do not add firmware-side calibration state machines.
- Do not add separate capture buttons such as `capture_soil_air` or `capture_soil_water`.
- Use `button.read_soil_raw_value` and HA scripts/automations to write final values.

### Consequences

- Firmware remains simpler.
- HA handles user workflow.
- Documentation must keep `soil_moisture_raw`, `soil_moisture_percent`, `soil_air`, `soil_water`, and `soil_depth_mm` aligned.

### Affected Areas

- `SPEC.md`
- `MODULES.md`
- `docs/entity-model.md`
- `sketches/Smaeenhouse/MoistureSensor.*`
- `sketches/Smaeenhouse/HAInterface.*`

## 2026-05 – Soil depth correction uses a simple linear model

Status: accepted

### Context

- The sensor response depends on insertion depth.
- A measurement series exists, and the project accepts the linear approximation as sufficient.

### Decision

- Use:
  - `depth_factor = soil_depth_mm / SOIL_REFERENCE_DEPTH_MM`
  - `percent = (soil_air - raw) / ((soil_air - soil_water) * depth_factor) * 100`
- Treat values below `SOIL_MIN_VALID_DEPTH_MM = 20` as invalid/unavailable for percent calculation.

### Consequences

- Raw value may still be published.
- Percent value should not be refreshed with misleading data when invalid.
- Future calibration improvements should be documented before changing the model.

### Affected Areas

- `SPEC.md`
- `MODULES.md`
- `docs/entity-model.md`
- `sketches/Smaeenhouse/Config.h`
- `sketches/Smaeenhouse/MoistureSensor.*`
- `sketches/Smaeenhouse/HAInterface.*`

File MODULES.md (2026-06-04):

## Technical Module Specification

## 1. Overall Architecture

The project is structured as an Arduino sketch under `sketches/Smaeenhouse/` with `.ino`, `.h`, and `.cpp` files.
The main sketch is located at `sketches/Smaeenhouse/Smaeenhouse.ino`; the related module and configuration files are located in the `sketches/Smaeenhouse/` folder.

Recommended files:

- `sketches/Smaeenhouse/Smaeenhouse.ino`
- `sketches/Smaeenhouse/Config.h`
- `sketches/Smaeenhouse/Credentials.h` (local, do not commit to the repository)
- `sketches/Smaeenhouse/PersistentConfig.h/.cpp`
- `sketches/Smaeenhouse/RtcEepromStorage.h/.cpp`
- `sketches/Smaeenhouse/SHTa.h/.cpp`
- `sketches/Smaeenhouse/FanController.h/.cpp`
- `sketches/Smaeenhouse/LightController.h/.cpp`
- `sketches/Smaeenhouse/MoistureSensor.h/.cpp`
- `sketches/Smaeenhouse/LightSensor.h/.cpp`
- `sketches/Smaeenhouse/ClockService.h/.cpp`
- `sketches/Smaeenhouse/NetworkManager.h/.cpp`
- `sketches/Smaeenhouse/HAInterface.h/.cpp`

### Basic Principle
Each module should preferably have this structure:

- `begin()`
- `update(uint32_t nowMs)`

`loop()` then only calls the `update()` methods.

## 2. Config.h

### Purpose
Central compile-time constants.

### Contents
- pin assignment
- default values
- measurement intervals
- dimmer resistance limits / brightness mapping
- default thresholds
- default schedule
- default soil calibration
- hardware notes for signal conditioning

### Typical Constants
- `PIN_SHT_ALERT`
- `PIN_RTC_ALARM`
- `PIN_FAN_SWITCH`
- `PIN_FAN_TACH`
- `PIN_LIGHT_DIM_SHDN`
- `PIN_LIGHT_POWER`
- `PIN_SOIL_SENSOR`
- `PIN_LIGHT_SENSOR_INT`

- `AD5263_I2C_ADDRESS = 0x2C`
- `AD5263_AD0_TO_GND = true`
- `AD5263_AD1_TO_GND = true`
- `TSL2591_I2C_ADDRESS = 0x29`
- `LIGHT_SENSOR_PUBLISH_INTERVAL_MS = 900000` (15 minutes / four samples per hour)
- `LIGHT_SENSOR_FAULT_FAILURE_COUNT`

- channel-specific effective RDAC limits for the used dimmer channels (`W2` and `W1`), for example:
  - `LIGHT_DIM_W2_RDAC_MIN_EFFECTIVE`
  - `LIGHT_DIM_W2_RDAC_MAX_EFFECTIVE`
  - `LIGHT_DIM_W1_RDAC_MIN_EFFECTIVE`
  - `LIGHT_DIM_W1_RDAC_MAX_EFFECTIVE`
- `LIGHT_DIM_MAPPING_SPLIT_PERCENT = 50` (split between W2 phase and W1 phase)
- Note: The identifiers are documented as examples; mandatory are the separate per-channel limits and the direction `minimal resistance = 0 %`, `maximal resistance = 100 %`.

- `DEFAULT_TEMP_HIGH_SET`
- `DEFAULT_TEMP_HIGH_CLEAR`
- `DEFAULT_HUM_HIGH_SET`
- `DEFAULT_HUM_HIGH_CLEAR`

- `DEFAULT_LIGHT_ON_TIME_MINUTES`
- `DEFAULT_LIGHT_OFF_TIME_MINUTES`
- `DEFAULT_LIGHT_DIM_MINUTES`

- `DEFAULT_SOIL_AIR`
- `DEFAULT_SOIL_WATER`
- `DEFAULT_SOIL_DEPTH_MM`
- `SOIL_DEPTH_MIN_MM = 0`
- `SOIL_REFERENCE_DEPTH_MM = 120`
- `SOIL_MIN_VALID_DEPTH_MM = 20`
- `SOIL_ADC_MIN = 0`
- `SOIL_ADC_MAX = 4095`

These soil constants complement the existing soil default values and do not replace them:

- `SOIL_REFERENCE_DEPTH_MM` is the reference depth at which water corresponds to `100 %`.
- `SOIL_DEPTH_MIN_MM` is the technical/persistence lower bound and defensive lower bound for stored or injected values.
- `SOIL_MIN_VALID_DEPTH_MM` is the first physical sensor marking, the minimum meaningful insertion depth, the normal Home Assistant UI minimum, and the lower limit below which the calculated percent value becomes invalid/unavailable.
- `SOIL_ADC_MIN` and `SOIL_ADC_MAX` are internal defensive limits for ADC raw values.

- `SOIL_PUBLISH_INTERVAL_MS = 10000`
- `TEMP_HUM_PUBLISH_INTERVAL_MS = 60000`
- `FAN_RPM_PUBLISH_INTERVAL_MS = 30000`

- `MQTT_FALLBACK_TIMEOUT_MS = 600000`

## 3. Credentials.h
### Purpose
Central storage for all credentials and installation-specific IDs.

### Contents
- WiFi SSID
- WiFi password
- MQTT host
- MQTT port
- MQTT user
- MQTT password
- Device Name
- Device Unique ID
- MQTT Prefix
- NTP server
- timezone information

## 4. PersistentConfig / External EEPROM Persistence

### Purpose
Persistent storage of all mutable runtime parameters in the **AT24C32 EEPROM**
of the WINGONEER Tiny DS3231 AT24C32 I2C module through the **JC_EEPROM** library.

### Data Structure
A central struct, for example `PersistentConfigData`, with:

- temp/hum thresholds
- Arduino light times
- Arduino dim duration
- `fanAutoMode`
- `lightAutoMode`
- fallback light behavior
- Soil Air/Water/Depth
- resume state for light recovery (separate substructure or clearly separated block) with:
  - last effective brightness
  - `hardPowerOffActive`
  - flag whether a HA dimming job was active
  - job start brightness
  - job target brightness
  - job duration
  - job start time on RTC/Epoch basis
- version number
- CRC/validation

### API
- `bool begin(TwoWire& wire = Wire);`
- `bool configureEeprom();`
- `bool load(PersistentConfigData& out);`
- `bool save(const PersistentConfigData& cfg);`
- `bool saveIfChanged(const PersistentConfigData& cfg);`
- `void applyDefaults(PersistentConfigData& cfg);`

### Requirements
- no unnecessary EEPROM writes
- save changes only when the value actually changed
- robust initialization when storage is empty/invalid
- encapsulate JC_EEPROM in project-specific logic, do not use it directly across the project
- never access EEPROM from an ISR
- The EEPROM I²C address is known and fixed for the project and is documented as '0x57'.
- The implementation should use this fixed address directly.
- There should be no automatic address search and no I²C scan during normal firmware initialization.
- The address is defined centrally as a constant, for example in `Config.h`.

### Technical Consequence
- The EEPROM wrapper or persistence class initializes `JC_EEPROM` directly with the known device address.
- Error handling refers to communication errors or invalid data, not to address search.
- Do not create existing configuration values a second time; extend persistence specifically with resume state.
- `millis()` is not sufficient for restart resumption; resume state requires an RTC/Epoch time base.

## 5. SHTa

### Purpose
Encapsulation of the SHT3x including threshold programming and alert evaluation.

### Reused Functions
- `begin()`
- `startPeriodicMeasurement(...)`
- `blockingReadMeasurement(...)`
- `decodeStatusRegister()`
- `clearStatus()`
- `writeHighLimit(...)`
- `writeHighClear(...)`
- `writeLowLimit(...)`
- `writeLowClear(...)`
- `readLimit(...)`
- `limitPrinter()`

### Additional Functional Responsibility
- writing configured thresholds to the sensor
- evaluating `alertTriggers[]`
- detecting sensor reset through `alertTriggers[4]`
- re-applying thresholds after reset

### API Extensions
Recommended:

- `void applyThresholdConfig(const PersistentConfigData& cfg);`
- `bool readMeasurement(float& temp, float& hum);`
- `bool hasTempAlert() const;`
- `bool hasHumAlert() const;`
- `bool hasSensorReset() const;`
- `void clearDecodedFlags();`

### ISR Rule
The actual I²C communication should **not happen in the ISR**.

Instead:
- ISR only sets a `volatile bool shtAlertPending`
- the main logic then calls `decodeStatusRegister()`

## 6. FanController

### Purpose
Switching the fan and measuring RPM.

### Responsibilities
- set fan switch pin
- count tach pulses for RPM
- implement auto/manual logic
- no own threshold calculations

### States
- `fanAutoMode`
- `fanManualState`
- `fanEffectiveState`
- `rpm`
- `fanFault`
- `tachPulseCount`

### API
- `void begin();`
- `void update(uint32_t nowMs);`
- `void setAutoMode(bool enabled);`
- `void setManualState(bool on);`
- `void setAutoDemand(bool on);`
- `bool isOn() const;`
- `uint16_t getRPM() const;`

### Control Logic
Effective fan state:

- if `fanAutoMode == true`: state follows `autoDemand`
- if `fanAutoMode == false`: state follows `manualState`

`autoDemand` is set **outside** the module from the SHT alert logic.

### RPM Logic
- tach ISR counts pulses
- calculate RPM every 30 s
- only when the fan should effectively be running
- set RPM to 0 on standstill if appropriate
- if the fan should effectively be on but no tach pulses arrive after the grace period: set `fanFault`

### Hardware Note: Fan Tach
The text documentation and the schematic should document the used 2N3904 stage:

- fan tach through 10 kΩ pull-up to 9 V
- tach through 47 kΩ to the base of a 2N3904
- 100 kΩ from base to GND
- emitter to GND
- collector to `PIN_FAN_TACH`
- 10 kΩ pull-up from collector to 3.3 V

The signal is inverted; the code selects the interrupt edge accordingly.

## 7. LightController

### Purpose
Control of AD5263 dimmer, SHDN pin, relay, and dimming requests.

### Central Responsibility
- clear separation between Arduino Auto and HA control
- management of the current brightness state (`0..100 %`)
- execution of dimming jobs
- AD5263 control via I²C outside ISRs
- use two AD5263 channels according to the fixed signal path
- SHDN control with safe boot behavior
- separate hard relay-off

### Mandatory Hardware Assumptions
- AD5263BRUZ50 in I²C mode (`DIS = 1`)
- fixed I²C address `0x2C` (`AD0 = GND`, `AD1 = GND`)
- pull-ups on SDA/SCL to `3.3 V`
- SHDN on `PIN_LIGHT_DIM_SHDN` with external `10 kΩ` pull-down
- no internal pull-up on SHDN
- analog channel wiring: `Dim+ -> W2 -> B2 -> A1 -> W1 -> Dim-`
- lamp dimmer input: minimal effective resistance / approximately `0 Ω` = `0 %`, maximal effective resistance / approximately `100 kΩ` = `100 %`

### Brightness Mapping (Mandatory)

Reference points:

- `0 %  => W2=0,   W1=255`
- `50 % => W2=0,   W1=0`
- `100 % => W2=255, W1=0`

Intermediate ranges:

- `0..50 %`: first change channel 1 / `W1` so the total resistance rises from the minimum value to the midpoint
- `50..100 %`: then change channel 2 / `W2` so the total resistance rises from the midpoint to the maximum value
- used rheostat stretches: `A1-W1` on channel 1 and `W2-B2` on channel 2

Dimmer limits:

- effective lower/upper limits are constrained through firmware constants
- `0 Ω` is to be understood as minimal effective resistance or approximately `0 Ω`, because the AD5263 has residual resistance in rheostat mode
- these limits are not configurable via HA

### Boot And Shutdown Sequence (Mandatory)

On startup:

1. Keep AD5263 in `SHDN`
2. Load configuration
3. Reconstruct target state from persisted data + resume state
4. Set RDAC resistance values
5. Release `SHDN`
6. Only then close relay

On shutdown:

1. Open relay
2. Put AD5263 into `SHDN`

Note:

- The AD5263 starts at midscale; without this sequence, an incorrect brightness start is possible.

### Important Internal States
- `lightAutoMode`
- `currentBrightnessPercent`
- `targetBrightnessPercent`
- `powerCutActive`
- `controlSource`:
  - `ARDUINO_AUTO`
  - `HA_CONTROL`
- current dimming job:
  - active/inactive
  - start brightness
  - target brightness
  - start time
  - duration
  - source
- `lightFault`
- `lightFaultReason`

### Resume State (Persisted)
At minimum:

- last effective brightness
- `hardPowerOffActive`
- flag whether a HA dimming job was active
- job start brightness
- job target brightness
- job duration
- job start time (RTC/Epoch-based)

Important:

- Resumption after restart must not be based only on `millis()`.

### API
- `void begin();`
- `void update(uint32_t nowMs);`

- `void setAutoMode(bool enabled);`
- `bool isAutoMode() const;`

- `void applyManualBrightness(uint8_t percent);`
- `void applyManualOnOff(bool on);`
- `void applyHardPowerOff(bool off);`

- `void startArduinoDimJob(uint8_t targetPercent, uint32_t durationMs);`
- `void startHADimJob(uint8_t targetPercent, uint32_t durationMs);`

- `uint8_t getCurrentBrightness() const;`
- `bool isPowerOn() const;`
- `bool hasLightFault() const;`
- `const char* getLightFaultReason() const;`

### Detailed Rules

#### With Auto Mode ON
- ignore `startHADimJob()`
- ignore `applyManualOnOff()` or treat it as no-op
- `applyManualBrightness()` may optionally override the current target value within the time window

#### With Auto Mode OFF
- ignore Arduino schedule events
- accept HA schedule dimming jobs and manual operation

#### Dimming Job Behavior
- a new job replaces the old job from the same active control world
- brightness is interpolated linearly over the runtime
- if `durationMs == 0`, set immediately
- at target `0 %`, power-off may optionally be set unless this is explicitly the separate hard-power-off switch

#### Hard Power Off
- only switches the relay
- does not change the stored brightness value

#### Fixed HA Dimming Job Interface
The HA dimming job is triggered mandatorily through these entities:

- `number.ha_dim_target_percent`
- `number.ha_dim_duration_minutes`
- `button.start_ha_dim`

### LightController Fault Strategy

Mandatory readback/plausibility strategy (staged and rate-limited):

1. Boot phase before `SHDN` release and before relay ON:
   - address AD5263
   - write defined W1/W2 RDAC values
   - check readback once
   - continue only if the result is consistent

2. For discrete commands:
   - manual brightness jump
   - start Arduino dimming job
   - start HA dimming job
   - restore from resume state
   in each case:
   - write
   - optional 1 short retry
   - check readback

3. For long dimming ramps:
   - no readback on every interpolation step
   - readback verification at the end of the ramp

Fault response (mandatory):

- AD5263 not reachable during boot:
  - relay remains open
  - light stays off
  - `lightFault = true`
  - `lightFaultReason = "ad5263_not_found"`

- AD5263 write failure after retry:
  - open relay
  - `lightFault = true`
  - `lightFaultReason = "ad5263_write_failed"`

- AD5263 readback mismatch after retry:
  - open relay
  - `lightFault = true`
  - `lightFaultReason = "ad5263_readback_mismatch"`

## 8. MoistureSensor

### Purpose
Reading and converting the soil moisture sensor.

### Responsibilities
- read raw value
- calculate calibrated percent value from Air/Water/Depth
- periodic 10 s measurement
- detect invalid percent values when insertion depth is too low

### States
- `soilAir`
- `soilWater`
- `soilDepth`
- `lastRaw`
- `lastPercent`
- `lastPercentValid` or equivalent validity flag
- `lastReadMs`

### API
- `void begin(int air, int water, int depthMm);`
- `void update(uint32_t nowMs);`
- `int readRawNow();`
- `int getLastRaw() const;`
- `uint8_t getLastPercent() const;`
- `bool isLastPercentValid() const;`
- `void setCalibration(int air, int water, int depthMm);`

### Rules
- `update()` reads every 10 s
- `readRawNow()` reads immediately, updates `lastRaw`, and enables `button.read_soil_raw_value`
- internal ADC raw values may defensively be constrained to `SOIL_ADC_MIN..SOIL_ADC_MAX` (`0..4095`)
- `soilAir` and `soilWater` remain persistent HA configuration values in the expected project range `0..1000` with step `1`
- `soilDepth` is an active correction parameter, not only an informational value
- HA normally exposes `soilDepth` as `20..120 mm`
- values below `20 mm` remain possible only as defensive stored/injected invalid state, not as a normal UI input path
- if `soilDepth < SOIL_MIN_VALID_DEPTH_MM`, the percent value is invalid/unavailable; the raw value may still be published
- no knowledge of the HA calibration routine is required
- no firmware buttons such as `capture_soil_air` or `capture_soil_water`

### Depth Correction
Definitions:

- `SOIL_REFERENCE_DEPTH_MM = 120`
- `SOIL_DEPTH_MIN_MM = 0`
- `SOIL_MIN_VALID_DEPTH_MM = 20`
- `soilAir`: raw value with sensor completely in air
- `soilWater`: raw value with sensor in water at 120 mm reference depth
- `soilDepth`: actual insertion depth in mm

Concept:

```text
depth_factor = soilDepth / SOIL_REFERENCE_DEPTH_MM
percent = (soilAir - raw) / ((soilAir - soilWater) * depth_factor) * 100
```

The air reference corresponds to `0 %`, and the water reference at `120 mm` corresponds to `100 %`. Valid percent values are constrained to `0..100 %`. The linear correction is intentionally sufficient for this project.

## 9. LightSensor

### Purpose
Reading the CQrobot CQRTSL25911 / TSL25911 cabinet light sensor.

### Responsibilities
- initialize the TSL25911 on I2C address `0x29`
- configure measurement timing and gain for broad cabinet-light measurements
- poll from normal loop code only
- keep the last valid lux and raw-channel readings
- expose a separate fault state after repeated read/initialization failures

### States
- `available`
- `fault`
- `lastSampleValid`
- `lastLux`
- `lastFullSpectrum`
- `lastInfrared`
- `lastVisible`
- `consecutiveReadFailures`
- `lastReadMs`

### API
- `void begin(TwoWire& wire);`
- `void update(uint32_t nowMs);`
- `void sampleNow();`
- `bool isAvailable() const;`
- `bool hasFault() const;`
- `bool hasValidSample() const;`
- `float getLastLux() const;`
- raw-channel getters for full spectrum, infrared, and visible

### Rules
- `update()` polls every `LIGHT_SENSOR_PUBLISH_INTERVAL_MS` (15 minutes / four samples per hour).
- The INT pin is reserved as `PIN_LIGHT_SENSOR_INT` and physically wired for future use, but firmware v1 does not attach an ISR.
- No I2C access may happen in an ISR.
- The light sensor is measurement-only in v1 and must not command the light.
- `light_sensor_fault` is separate from `light_fault`; a broken light sensor must not block existing light operation.
- Real measurement histories and HA exports are sensitive local data and must not be committed.

### Future Lux-Hour Assistance
The sensor is intended to support a later HA-first light-sum design. HA can combine cabinet illuminance, the outside brightness sensor, current grow-light brightness, and time of day to derive gradual compensation targets.

The future control model should use existing HA dimming entities while `light_auto_mode = OFF`. It should avoid end-of-day catch-up at full power and instead distribute corrections according to expected brightness for the current time of day. Standalone/fallback lux-based behavior remains out of scope until separately designed.

## 10. ClockService

### Purpose
Management of RTC_DS3231, its alarms, and NTP synchronization.

### Responsibilities
- initialize RTC
- fetch NTP time
- set RTC
- provide current time
- configure DS3231 SQW/INT for alarm operation
- mirror daily alarm times into the RTC register
- evaluate and acknowledge alarm flags
- trigger daily re-sync

### States
- `lastSuccessfulSyncMs`
- `rtcAvailable`
- `timeValid`
- `alarmsConfigured`
- internal NTP failure reason for serial diagnostics

### API
- `void begin();`
- `void update(uint32_t nowMs);`
- `bool syncFromNTP();`
- `DateTime now() const;`
- `uint16_t minutesSinceMidnight() const;`
- `bool isTimeValid() const;`
- `bool configureScheduleAlarms(uint16_t onMinutes, uint16_t offMinutes);`
- `ClockAlarmEvent serviceAlarmFlags();`

### Recommended Alarm Event Type
```cpp
enum class ClockAlarmEvent {
    None,
    LightOnAlarm,
    LightOffAlarm
};
```

### Implementation Notes
- Use RTClib functions of the DS3231:
  - `writeSqwPinMode(...)`
  - `setAlarm1(...)`
  - `setAlarm2(...)`
  - `alarmFired(...)`
  - `clearAlarm(...)`
- SQW/INT is an open-drain output; operate the Arduino side with `INPUT_PULLUP`.
- If the line proves noise-sensitive in the real build, an additional external 10 kΩ pull-up to 3.3 V may be added.

### Rules
- sync during boot
- afterwards at least every 24 h
- manual sync command from HA possible
- reprogram alarm registers after time sync or configuration change
- I²C access only outside the ISR
- current UDP NTP sync may block briefly while waiting for a response; this is acceptable during boot, manual sync, and daily resync
- default NTP server remains `pool.ntp.org`
- serial diagnostics distinguish DNS, UDP setup/send, missing response, short response, and invalid timestamp failures
- `WiFi.getTime()` may be used as a secondary module-time fallback/check after explicit UDP NTP failure
- NTP diagnostics do not create additional HA entities

## 11. NetworkManager

### Purpose
Manage WiFi and MQTT connection.

### Responsibilities
- connect WiFi
- connect MQTT
- reconnect strategy
- measure offline duration
- detect fallback condition after 10 min

### States
- `wifiConnected`
- `mqttConnected`
- `lastConnectionOkMs`
- `fallbackActive`
- WiFi reconnect state
- WiFi reconnect attempt counter

### API
- `void begin();`
- `void update(uint32_t nowMs);`
- `bool isWifiConnected() const;`
- `bool isMqttConnected() const;`
- `bool isOnline() const;`
- `bool isFallbackActive() const;`

### Rules
- periodic reconnect attempts
- WiFi reconnect starts with forced disconnect and a short settle interval
- WiFi connect attempts are bounded by configured attempt count and timeout constants
- online = WiFi + MQTT ok
- if offline >10 min: `fallbackActive = true`
- on successful connection again: `fallbackActive = false`

## 12. HAInterface

### Purpose
Mapping of all HA entities and processing of HA commands.

### Responsibilities
- Discovery / device setup
- publishing states and measurements
- receiving commands
- state re-publish after MQTT reconnect
- periodic MQTT reconnect attempts while WiFi is connected

### Required References
The module should be able to access other modules, for example by reference in the constructor:

- `FanController&`
- `LightController&`
- `MoistureSensor&`
- `LightSensor&`
- `ClockService&`
- `SHTa&`
- `PersistentConfigManager&`
- `NetworkManager&`

### HA Entities
- `HADevice`
- `HAMqtt`
- `HASensorNumber` for temperature, humidity, `sensor.soil_moisture_percent`, `sensor.soil_moisture_raw`, cabinet illuminance/raw light channels, RPM
- `HABinarySensor` for `light_fault`, `fan_fault`, `sht_fault`, `rtc_fault`, `eeprom_fault`, `light_sensor_fault`
- `HASensor` (text) for `light_fault_reason`
- `HASwitch` for Fan, FanAuto, LightAuto, HardPowerOff, fallback behavior
- `HALight` for Grow-Light
- `HANumber` for thresholds, times, dim duration, `number.soil_air`, `number.soil_water`, `number.soil_depth_mm`
- `HANumber` for `ha_dim_target_percent`
- `HANumber` for `ha_dim_duration_minutes`
- `HAButton` for `sync_time`
- `HAButton` for `read_soil_raw_value`
- `HAButton` for `start_ha_dim`

Separate soil capture buttons such as `capture_soil_air` or `capture_soil_water` are not part of the HA entity model. HA uses `read_soil_raw_value` and writes the read value into `soil_air` or `soil_water` by script/automation.

### API
- `void begin();`
- `void update(uint32_t nowMs);`
- `void onMqttConnected();`

### Additional Helper Functions
- `void publishAllStates();`
- `void publishSensorValues();`
- `void publishConfigValues();`

### Additional Internal States For HA Dimming Job
- `uint8_t pendingHaDimTargetPercent;`
- `uint16_t pendingHaDimDurationMinutes;`

### Rules
- on reconnect, publish all relevant states again
- the ArduinoHA MQTT entity registration limit must cover every documented production entity plus reserve
- light and switch states are sufficient; no separate sensor for actual light brightness or light mode is required
- `start_ha_dim` validates:
  - target 0..100
  - duration 0..1440 minutes
- then calls:
  - `lightController.startHADimJob(target, durationMs)`

### Persistence Note
The values for:
- `ha_dim_target_percent`
- `ha_dim_duration_minutes`

are **not persistent**, but only runtime/command parameters.
- A running HA dimming job can be made reconstructable after restart through the persisted resume state (start/target/duration/start time).

### System-Level Fault Status
The firmware documentation uses the following fault states:

- `light_fault`
- `fan_fault`
- `sht_fault`
- `rtc_fault`
- `eeprom_fault`
- `light_sensor_fault`

Do not use:

- `sensor_fault`
- `system_fault`
- `last_fault_code`

Additional text status (as text `sensor`):

- `light_fault_reason`

## 13. Smaeenhouse.ino

### Purpose
Central orchestration.

### Responsibilities
- global module instances
- setup order
- ISR flags
- call order in `loop()`

### Setup Order
1. Serial
2. Wire
3. Load persistent configuration from AT24C32 or defaults
4. Construct/initialize modules
5. Apply SHT thresholds
6. Initialize RTC and configure alarms
7. Start network/HA
8. Try first NTP sync
9. Enable interrupts

### Loop Order
1. `nowMs = millis()`
2. `network.update(nowMs)`
3. `clock.update(nowMs)`
4. check `sht` alert flag and evaluate status
5. from that, call `fan.setAutoDemand(...)`
6. check `rtcAlarmPending` and run `clock.serviceAlarmFlags()`
7. from that, start `light.startArduinoDimJob(...)` if needed
8. `fan.update(nowMs)`
9. `light.update(nowMs)`
10. `moisture.update(nowMs)`
11. `lightSensor.update(nowMs)`
12. `ha.update(nowMs)`

## 14. ISR Strategy

There should be three ISR-adjacent flags:

- `volatile bool shtAlertPending`
- `volatile bool rtcAlarmPending`
- tach ISR in FanController only for pulse counting
- light sensor INT is reserved for future use but does not attach an ISR in v1

Important:
- no I²C operation in ISR
- no MQTT/HA operation in ISR
- no expensive logic in ISR

## 15. Logical Core Flows

### SHT Alert → Fan
1. Pin 7 interrupt sets flag
2. Main loop reads sensor status
3. If reset bit is set → write thresholds again
4. If temp or hum alert active → `fan.setAutoDemand(true)`
5. If no relevant alerts are active → `fan.setAutoDemand(false)`

### RTC Alarm → Arduino Light Schedule
1. DS3231 SQW/INT on `PIN_RTC_ALARM` sets interrupt flag
2. Main loop calls `clock.serviceAlarmFlags()`
3. `alarmFired(1)` / `alarmFired(2)` determine which alarm fired
4. Alarm flag is cleared
5. Depending on the event, the corresponding Arduino dimming request is started

### HA Light Operation
1. If `lightAutoMode == OFF`, LightController accepts HA commands
2. HA schedule starts explicit dimming jobs
3. Manual slider/on-off commands act directly

### Fallback
1. NetworkManager detects offline >10 min
2. depending on configuration:
   - turn light off
   - or activate internal Auto Mode
3. local functions continue running

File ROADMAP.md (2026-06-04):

# Roadmap

This file tracks open work, next steps, validation needs, and optional improvements. It is intentionally separate from `README.md`, `SPEC.md`, `MODULES.md`, and `docs/entity-model.md`, which describe the current target system.

## Immediate Validation

- Run an Arduino IDE compile/build check for the main sketch.
- Verify the repository script compile path with `scripts/check-arduino`.
- Run or verify the AD5263 bench test sketch after the corrected mapping.
- Verify that the current code and documentation stay aligned before merging.

## Firmware Follow-Up

- Check whether invalid `soil_moisture_percent` can be represented as truly unavailable in ArduinoHA.
- Current fallback behavior: keep publishing raw values and avoid refreshing a misleading percent value if the percent calculation is invalid.
- Consider whether changing `soil_air`, `soil_water`, or `soil_depth_mm` from HA should trigger an immediate `sampleNow()` and state publish instead of waiting for the next interval or manual raw read.
- Verify AD5263 readback/fault behavior on real hardware.
- Verify resume-state behavior after restart for manual mode, HA dim jobs, and Arduino auto mode.

## Hardware Validation

- Validate AD5263 mapping and effective lower/upper resistance limits with the real lamp driver.
- Validate SHDN behavior and relay sequencing.
- Validate fan tach fault detection.
- Validate soil moisture depth correction with real sensor placement.
- Validate CQRTSL25911 placement, I2C address `0x29`, INT wiring on `PIN_LIGHT_SENSOR_INT`, and useful lux/raw ranges with lamp off and at representative dim levels.
- Validate production WiFi reconnect after sketch upload or WiFiNINA module state transitions.
- Validate production MQTT reconnect after broker outage while WiFi stays connected.
- Validate production NTP serial diagnostics for success and representative failure cases.

## Home Assistant Follow-Up

- Implement or update HA dashboard/scripts separately from this firmware branch.
- Add HA automations for the documented `button.read_soil_raw_value` calibration workflow.
- Confirm that fault entities are displayed clearly in HA.
- Ensure any future diagnostic HA device uses diagnostic-specific entity IDs and does not reuse production MQTT discovery unique IDs.
- Use HA history to design future lux-hour assistance from cabinet illuminance, the outside brightness sensor, grow-light brightness, and time of day.

## Optional Improvements

- Consider replacing the brief blocking UDP NTP wait with a non-blocking NTP state machine.
- Consider introducing a single machine-readable dependency source used by setup and check scripts. Keep `libraries.txt` as human-readable dependency documentation unless or until that source is introduced.
- Consider a dedicated validity indicator for soil percent if HA cannot show unavailable cleanly.
- Consider a compact diagnostic view for current AD5263 codes or derived dimmer resistance, if useful later.
- Consider a small decision-log review before major future refactors.

## Done / Recently Aligned

- Production WiFi reconnect now forces disconnect, waits a settle interval, and uses bounded timeout-based connect attempts.
- Production MQTT reconnect now retries periodically while WiFi is connected.
- Production NTP diagnostics now distinguish DNS, UDP setup/send, missing response, short response, invalid timestamp, and `WiFi.getTime()` fallback/check outcomes.
- Network diagnostics sketch added for WiFi, DNS, MQTT, Home Assistant discovery, and NTP checks.
- External NTP validation confirmed `pool.ntp.org` as the preferred configured NTP server.
- Documentation translated to English.
- AD5263 mapping aligned to tested lamp direction.
- Soil entity names aligned to `soil_moisture_percent` and `soil_moisture_raw`.
- Soil depth correction added to documentation and firmware.
- AD5263 test sketch aligned with the corrected mapping.

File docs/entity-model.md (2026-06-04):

# Home Assistant Entity Model

This file describes the planned Home Assistant entities and their meaning.

## Device

A single HA device:

- Name: `Grow Controller`
- Platform: ArduinoHA / MQTT Discovery

## Sensors

### Temperature
- Entity type: `sensor`
- Name: `temperature`
- Direction: Arduino → HA
- Unit: `°C`

### Humidity
- Entity type: `sensor`
- Name: `humidity`
- Direction: Arduino → HA
- Unit: `%`

### Soil Moisture Percent
- Entity type: `sensor`
- Name: `soil_moisture_percent`
- Direction: Arduino → HA
- Unit: `%`
- Meaning:
  - calculated value from `soil_air`, `soil_water`, current raw value, and `soil_depth_mm`
  - air reference corresponds to `0 %`
  - water reference at `120 mm` corresponds to `100 %`
  - valid values are constrained to `0..100 %`
  - if `soil_depth_mm < 20`, the value should be unavailable/invalid

### Soil Moisture Raw Value
- Entity type: `sensor`
- Name: `soil_moisture_raw`
- Direction: Arduino → HA
- Unit: raw / analog
- Meaning:
  - current ADC-related raw value of the sensor
  - may also be published when percent calculation is invalid

### Fan RPM
- Entity type: `sensor`
- Name: `fan_rpm`
- Direction: Arduino → HA
- Unit: `rpm`

### Cabinet Illuminance
- Entity type: `sensor`
- Name: `cabinet_illuminance_lux`
- Direction: Arduino → HA
- Unit: `lx`
- Meaning:
  - illuminance measured inside the plant cabinet by the CQRTSL25911 / TSL25911 sensor
  - measurement-only in the initial integration
  - may be used later by HA together with an outside brightness sensor and `grow_light` brightness history for lux-hour assistance

### Cabinet Light Raw Channels
- Entity type: `sensor`
- Names:
  - `cabinet_light_full_spectrum_raw`
  - `cabinet_light_infrared_raw`
  - `cabinet_light_visible_raw`
- Direction: Arduino → HA
- Unit: raw sensor counts
- Meaning:
  - diagnostic raw-channel values from the light sensor
  - useful for checking saturation, placement, and relation between lamp brightness and measured cabinet light

## Fault Entities

### Light Fault
- Entity type: `binary_sensor`
- Name: `light_fault`
- Direction: Arduino → HA
- Meaning:
  - fault in the light path, especially AD5263/I²C/readback related

### Fan Fault
- Entity type: `binary_sensor`
- Name: `fan_fault`
- Direction: Arduino → HA
- Meaning:
  - fan should effectively be running, but no tach pulses after grace period

### SHT Fault
- Entity type: `binary_sensor`
- Name: `sht_fault`
- Direction: Arduino → HA
- Meaning:
  - SHT3x communication or sensor status is problematic

### RTC Fault
- Entity type: `binary_sensor`
- Name: `rtc_fault`
- Direction: Arduino → HA
- Meaning:
  - DS3231 unavailable or time-base problem

### EEPROM Fault
- Entity type: `binary_sensor`
- Name: `eeprom_fault`
- Direction: Arduino → HA
- Meaning:
  - AT24C32 unavailable or persistence problem

### Light Sensor Fault
- Entity type: `binary_sensor`
- Name: `light_sensor_fault`
- Direction: Arduino → HA
- Meaning:
  - CQRTSL25911 / TSL25911 initialization or read failures
  - separate from `light_fault`; existing light operation should continue if only the light sensor fails

### Light Fault Reason
- Entity type: `sensor` (text)
- Name: `light_fault_reason`
- Direction: Arduino → HA
- Meaning:
  - textual cause for `light_fault`
- Examples:
  - `ad5263_not_found`
  - `ad5263_write_failed`
  - `ad5263_readback_mismatch`

The detailed AD5263 readback and retry strategy is described in `MODULES.md`.

Not part of the model:

- `sensor_fault`
- `system_fault`
- `last_fault_code`

## Measurement Data Privacy

Real measurement histories are sensitive data. Home Assistant exports, timestamped lux histories, calibration tables, and derived analysis datasets from the real room or cabinet must stay local and must not be committed or pushed to GitHub.

Documentation may include synthetic, anonymized, or highly summarized examples when needed.

## Switches

### Fan Switch
- Entity type: `switch`
- Name: `fan`
- Direction: HA ↔ Arduino
- Meaning:
  - manual fan on/off

### Fan Auto Mode
- Entity type: `switch`
- Name: `fan_auto_mode`
- Direction: HA ↔ Arduino
- Meaning:
  - ON: SHT alert controls the fan
  - OFF: manual fan control

### Light Auto Mode
- Entity type: `switch`
- Name: `light_auto_mode`
- Direction: HA ↔ Arduino
- Meaning:
  - ON: Arduino schedule via DS3231 alarms active
  - OFF: HA control active

### Light Hard Power Off
- Entity type: `switch`
- Name: `light_hard_power_off`
- Direction: HA ↔ Arduino
- Meaning:
  - always-available safety override
  - may act in both Arduino Auto Mode and HA-controlled mode
  - switches the relay immediately
  - dimmer state is retained internally
- Dashboard note:
  - should not be hidden in the associated light/control cards based on light mode

### Fallback Behavior
- Entity type: `switch`
- Name: `light_fallback_to_auto`
- Direction: HA ↔ Arduino
- Meaning:
  - ON: activate internal Arduino Auto Mode for the light during longer offline state
  - OFF: turn light off during longer offline state

## Light

### Grow Light
- Entity type: `light`
- Name: `grow_light`
- Direction: HA ↔ Arduino
- Functions:
  - ON/OFF
  - Brightness

### Important Rule
The Light entity is only fully effective when:

- `light_auto_mode = OFF`

When `light_auto_mode = ON`:
- brightness changes may optionally be treated as temporary correction
- HA schedule triggers are ignored
- on/off may be ignored or disabled

## Future Lux-Hour Assistance

The cabinet light sensor is intended to support later HA-side light-sum control, not immediate firmware-side control.

Future HA automations may combine:

- `sensor.cabinet_illuminance_lux`
- an outside brightness sensor already available in HA
- `light.grow_light` state and brightness
- time of day and the current schedule window

The intended behavior is gradual compensation based on expected light at the current time of day. It should avoid waiting until the end of the day and then switching the grow light to full power to compensate for a low daily total.

In standalone or fallback modes, the firmware should initially keep the existing schedule/fallback behavior. Any lux-based local fallback must be designed separately and bounded to the Arduino schedule window.

## Number Entities

### Temperature / Humidity Thresholds
- `temp_high_set`
- `temp_high_clear`
- `temp_low_set`
- `temp_low_clear`
- `hum_high_set`
- `hum_high_clear`
- `hum_low_set`
- `hum_low_clear`

Direction:
- HA ↔ Arduino

Persistence:
- yes, external AT24C32 EEPROM via JC_EEPROM

### Arduino Light Schedule
- `light_on_time_minutes`
- `light_off_time_minutes`
- `light_dim_minutes`

Direction:
- HA ↔ Arduino

Persistence:
- yes, external AT24C32 EEPROM via JC_EEPROM

Note:
- time format = minutes since midnight
- changes must also update the DS3231 alarm registers

### Soil Moisture Calibration
- `soil_air`
- `soil_water`
- `soil_depth_mm`

Direction:
- HA ↔ Arduino

Persistence:
- yes, external AT24C32 EEPROM via JC_EEPROM

Limits:

- `soil_air`: min 0, max 1000, step 1
- `soil_water`: min 0, max 1000, step 1
- `soil_depth_mm`: normal HA user-facing range 20..120 mm, step 1

Note:

- `soil_air` and `soil_water` use the expected real project range; air values are expected below approx. 900.
- The firmware may set separate hard internal ADC safety limits to `0..4095`.
- `soil_depth_mm` is an active correction parameter, not merely informational.
- `SOIL_DEPTH_MIN_MM = 0` remains the technical/persistence lower bound and defensive lower bound for stored or injected values.
- `SOIL_MIN_VALID_DEPTH_MM = 20` is the first physical sensor marking, the minimum meaningful insertion depth, and the Home Assistant UI minimum.
- Values below `20 mm` are invalid for percent calculation because the first physical sensor marking is at `20 mm`.
- Values below `20 mm` are only a defensive invalid state, not a normal UI input path.
- Water reference is `120 mm`.

Conceptual percent calculation:

```text
SOIL_REFERENCE_DEPTH_MM = 120
depth_factor = soil_depth_mm / SOIL_REFERENCE_DEPTH_MM
percent = (soil_air - raw) / ((soil_air - soil_water) * depth_factor) * 100
```

Valid percent values are constrained to `0..100 %`. If `soil_depth_mm < 20`, `sensor.soil_moisture_percent` remains unavailable/invalid; `sensor.soil_moisture_raw` may continue to be published.

The linear depth correction is a deliberate approximation. A measurement series exists,
but the project currently accepts this model as sufficiently accurate.

### HA Dimming Request
- `ha_dim_target_percent`
- `ha_dim_duration_minutes`

Direction:
- HA → Arduino

Persistence:
- no

Meaning:
- runtime/command parameters for an explicit HA dimming job
- become effective only when `start_ha_dim` is triggered
- resumption of a running HA dimming job after restart happens through the internally persisted resume state (not through the Number states themselves)

## Buttons

### Sync Time
- Entity type: `button`
- Name: `sync_time`
- Direction: HA → Arduino
- Effect:
  - trigger NTP sync
  - update RTC
  - rewrite DS3231 alarms

### Read Soil Raw Value
- Entity type: `button`
- Name: `read_soil_raw_value`
- Direction: HA → Arduino
- Effect:
  - immediately read and publish current raw value
  - intended for HA-guided calibration
  - HA then writes the published raw value to `number.soil_air` or `number.soil_water`

Separate buttons such as `capture_soil_air` or `capture_soil_water` are not part of the model.

### Start HA Dim
- Entity type: `button`
- Name: `start_ha_dim`
- Direction: HA → Arduino
- Effect:
  - starts a dimming request from the current actual brightness
  - target = `ha_dim_target_percent`
  - duration = `ha_dim_duration_minutes`

### Important Rule
`start_ha_dim` is only effective when:

- `light_auto_mode = OFF`

When `light_auto_mode = ON`, the command is ignored.

## Soil Moisture Calibration Workflow

The firmware does not manage a calibration assistant and does not contain an internal
calibration state machine. Home Assistant orchestrates the workflow with the
generic button `read_soil_raw_value` and the three persistent Number entities.

Air step:
- The user places the sensor dry in air.
- HA calls `button.read_soil_raw_value`.
- HA waits briefly until `sensor.soil_moisture_raw` is updated.
- HA writes this value to `number.soil_air`.

Water step:
- The user places the sensor in water at the reference depth of `120 mm`.
- HA calls `button.read_soil_raw_value`.
- HA waits briefly until `sensor.soil_moisture_raw` is updated.
- HA writes this value to `number.soil_water`.

Depth step:
- The user manually enters the actual insertion depth in the substrate in `number.soil_depth_mm`.
- The firmware actively uses this value for percent calculation.

Separate firmware buttons such as `capture_soil_air` or `capture_soil_water`
should not be added. The generic raw-read button plus HA scripts or
HA automations is sufficient and avoids unnecessary MQTT entities.

## State Recovery / Re-Publish

After startup or MQTT reconnect, the following should be actively published again:

- switch states
- light state
- number configuration values
- fault states including `light_fault_reason`
- current sensor values

Therefore separate diagnostic sensors for:

- actual light brightness
- light mode

are not strictly required.

## Optional Future Diagnostic Entities

Only if desired:

- active light control mode
- current AD5263 code or derived dimmer resistance
- fallback active
- last NTP sync time
- RTC alarm state

These are optional and not part of the mandatory scope.

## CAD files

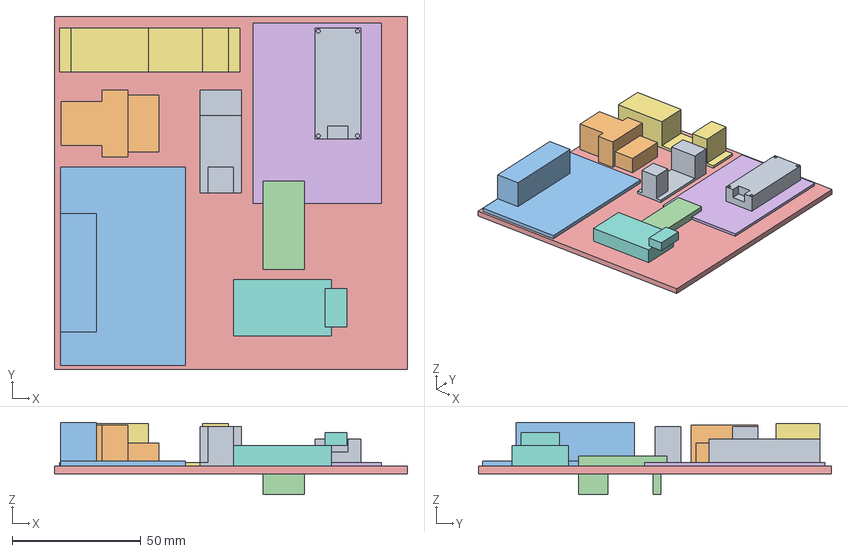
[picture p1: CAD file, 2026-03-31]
CAD/Vitrine.FCStd
137.0 x 137.0 x 28.0 mm
Nano
RJ12
PowerSupply
SolidStateRelais
Untergrund
Perfboard
Relais
RTC
Opto

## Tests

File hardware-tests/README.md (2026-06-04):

# Hardware Tests

Manual hardware validation sketches belong here.

Hardware tests are separate from production firmware. They validate wiring, libraries, pin assignments, signal levels, timing behavior, and module assumptions before production modules rely on those assumptions.

Hardware tests normally run locally on real hardware. They can document expected compile behavior and intended Serial output, but they cannot be fully validated in CI because sensors, actuators, signal levels, and timing behavior depend on the physical build.

## Available Sketches

- `AD5263Test`
- `ClockServiceTest`
- `FanControllerTest`
- `HAInterfaceTest`
- `LightControllerTest`
- `MoistureSensorTest`
- `NetworkDiagnosticsTest`
- `NetworkManagerTest`
- `PersistentConfigTest`
- `ShtModuleTest`

`ClockServiceTest`, `NetworkManagerTest`, and `HAInterfaceTest` use credential-dependent modules. Compile checks can temporarily use the production `Credentials.example.h`; uploads to real hardware need real local credentials copied into the test folder or otherwise provided.

`NetworkDiagnosticsTest` is different: it does not include production credentials. Edit the `TEST_*` placeholders at the top of its sketch locally before uploading.

## Compile Checks

Run `scripts/setup-arduino` once per local machine before compile checks. Normal compile checks should not download, install, or update Arduino cores or libraries.

Default production compile:

- Windows: `.\scripts\check-arduino.ps1`
- Linux/macOS: `./scripts/check-arduino.sh`

The default production sketch is `sketches/Smaeenhouse`.

Hardware test compile:

- Windows PowerShell:
  - `$env:SKETCH = "hardware-tests/<test-folder>"`
  - `.\scripts\check-arduino.ps1`
- Linux/macOS: `SKETCH=hardware-tests/<test-folder> ./scripts/check-arduino.sh`

Hardware test folders normally do not contain their own `sketch.yaml`; therefore the scripts compile them with the `FQBN` fallback. If a future test needs its own profile, add a local `sketch.yaml` to that test folder deliberately.

## Test Folder Rules

- Keep tests small.
- Cover one hardware topic per test.
- Keep test-only code out of production firmware.
- Document wiring before uploading a test sketch.
- Document expected Serial output.
- Document safety notes before actuating hardware.
- Never test mains wiring from a sketch without a safe physical setup.
- Copy findings that change requirements or validate assumptions back into `SPEC.md`, `HARDWARE.md`, `ROADMAP.md`, or `DECISIONS.md`.

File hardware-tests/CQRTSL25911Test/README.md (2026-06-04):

# CQRTSL25911Test

Minimal bench test for the CQrobot CQRTSL25911 / TSL25911 cabinet light sensor.

## Purpose

This sketch validates the light sensor before production firmware depends on it.

It checks:

- I2C communication with the sensor at address `0x29`
- basic lux calculation through the Adafruit TSL2591 library
- raw full-spectrum, infrared, and derived visible-channel values
- the prepared INT line on Arduino D9 as a normal input

The sketch intentionally uses polling only. It does not attach an ISR and does not perform interrupt-driven I2C access.

## Wiring

- `VIN` / `VCC`: 3.3 V-compatible sensor supply according to the module wiring
- `GND`: common logic ground
- `SDA/SCL`: shared project I2C bus
- `INT`: Arduino D9 / future `PIN_LIGHT_SENSOR_INT`

The production schematic in `FullArduinoHouse.fzz` is the primary wiring reference.

## Running The Test

Compile:

```powershell
$env:SKETCH = "hardware-tests/CQRTSL25911Test"
.\scripts\check-arduino.ps1
```

Upload the sketch to the Arduino Nano 33 IoT and open Serial at `115200 baud`.

Expected startup output:

- test header
- expected I2C address `0x29`
- prepared INT pin `D9`
- `Sensor initialized.`

Expected periodic output:

- `Lux`
- `Full spectrum raw`
- `Infrared raw`
- `Visible raw`
- `INT pin D9`

## Captured Result

`OUTPUT.txt` contains one captured hardware run.

Observed results from that run:

- The sensor initialized successfully at `0x29`.
- 31 samples were captured.
- Lux ranged from `0.00 lx` to `2513.81 lx`.
- Average lux over the captured run was approximately `904.61 lx`.
- Full-spectrum raw values ranged from `1` to `1102`.
- Infrared raw values ranged from `1` to `278`.
- Derived visible raw values ranged from `0` to `824`.
- The prepared INT line on D9 stayed `HIGH` throughout the run.

Interpretation:

- Basic I2C communication and library-based lux conversion work.
- The sensor reacted clearly to dark, medium, and brighter light conditions.
- The D9 INT wire appears electrically idle/high in this polling-only test, which is acceptable for the current firmware because no interrupt behavior is used yet.
- The captured values are suitable as first plausibility data, but not as final cabinet calibration. Future validation should repeat measurements with known lamp dimming levels and final sensor placement.

## Notes

Keep future real measurement histories local unless a short validation capture is deliberately added as a project artifact. Do not commit Home Assistant exports, long timestamped histories, or derived private environment datasets.

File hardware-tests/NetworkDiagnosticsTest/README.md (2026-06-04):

# NetworkDiagnosticsTest

Standalone Arduino Nano 33 IoT network diagnostics sketch.

This test intentionally does not include the production `Credentials.h` file. Before uploading to real hardware, edit the `TEST_*` constants at the top of `NetworkDiagnosticsTest.ino` with local WiFi, MQTT, device, and NTP values.

The sketch checks:

- WiFi connection details
- forced WiFi reconnect with retry, useful after uploading while an older sketch was running
- DNS resolution for MQTT and NTP hosts
- TCP connectivity to the MQTT broker
- detailed NTP UDP request/response behavior across configurable servers
- standard and legacy NTP request headers for comparing server behavior
- WiFiNINA module time via `WiFi.getTime()` as an independent NTP-side check
- ArduinoHA MQTT connection and simulated Home Assistant entities

Serial commands:

- `h` print help
- `w` rerun WiFi, DNS, and MQTT TCP diagnostics
- `n` rerun detailed NTP diagnostics, including `WiFi.getTime()`
- `m` reconnect MQTT
- `p` publish all simulated Home Assistant states
- `r` rotate synthetic sensor values and publish
- `a` toggle diagnostic availability

Compile check:

```powershell
$env:SKETCH = "hardware-tests/NetworkDiagnosticsTest"
.\scripts\check-arduino.ps1
```

The local `Credentials.example.h` in this folder is a placeholder for the repository compile script only. The sketch does not include it.

## Findings

- `pool.ntp.org` is the preferred default external NTP server for this project.
- After uploading a new sketch while an older network test was running, the first WiFi connection attempt may fail because the WiFiNINA module still appears to be in an old connection state. This test intentionally forces `WiFi.disconnect()`, waits briefly, and retries before reporting WiFi failure.
- `WiFi.getTime()` is useful as an independent NTP-side check because it asks the WiFiNINA module for its own synchronized Unix time. A zero result means the module has no usable time.
- Diagnostic Home Assistant entities must use diagnostic-specific device/entity identifiers. Reusing production-style unique IDs can collide with old or production MQTT discovery entries in the Home Assistant entity registry.
- Network infrastructure policy is outside this repository. The firmware expectation is simply that the configured NTP server, normally `pool.ntp.org`, is reachable from the device over UDP port `123`.

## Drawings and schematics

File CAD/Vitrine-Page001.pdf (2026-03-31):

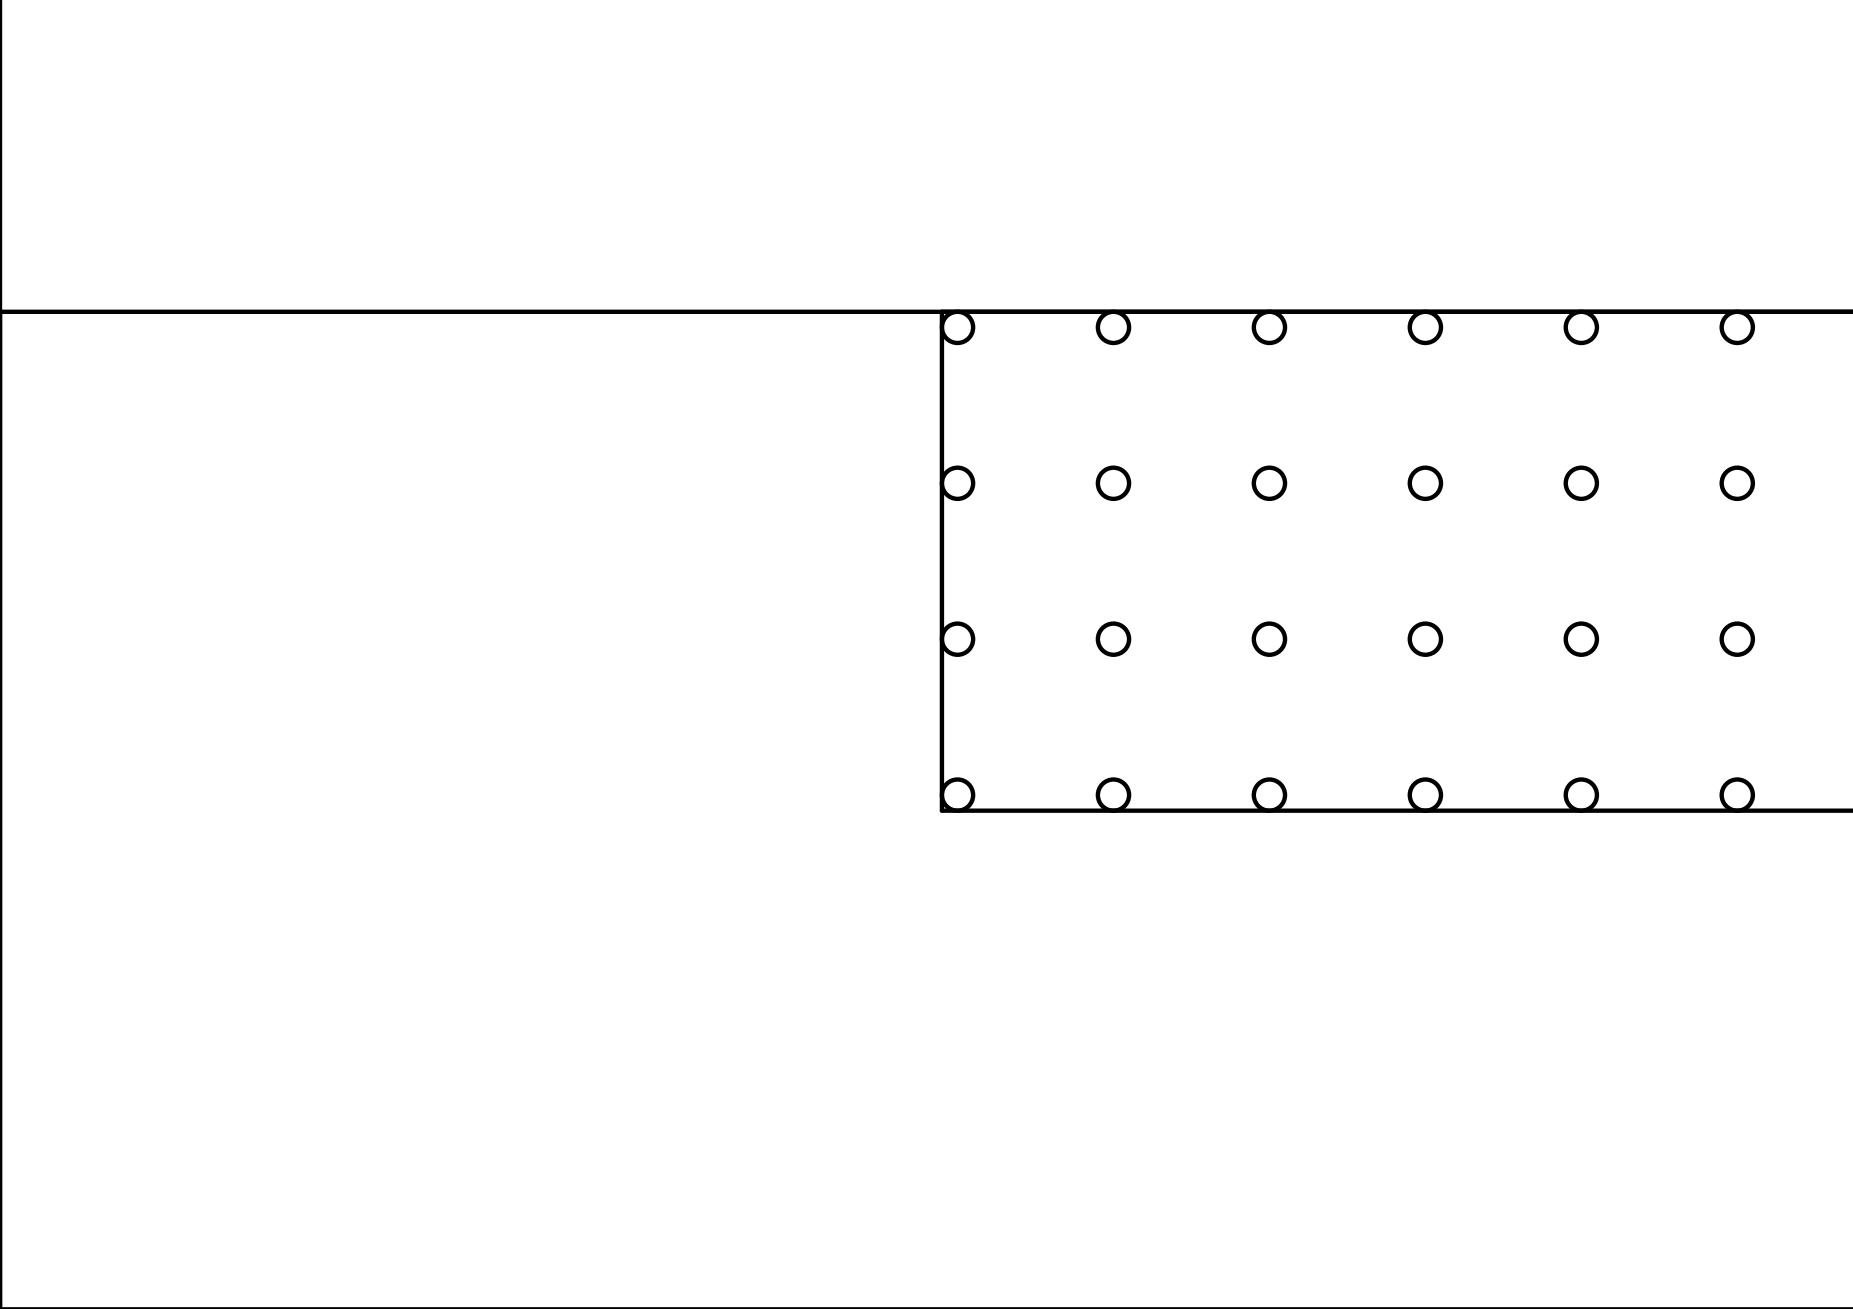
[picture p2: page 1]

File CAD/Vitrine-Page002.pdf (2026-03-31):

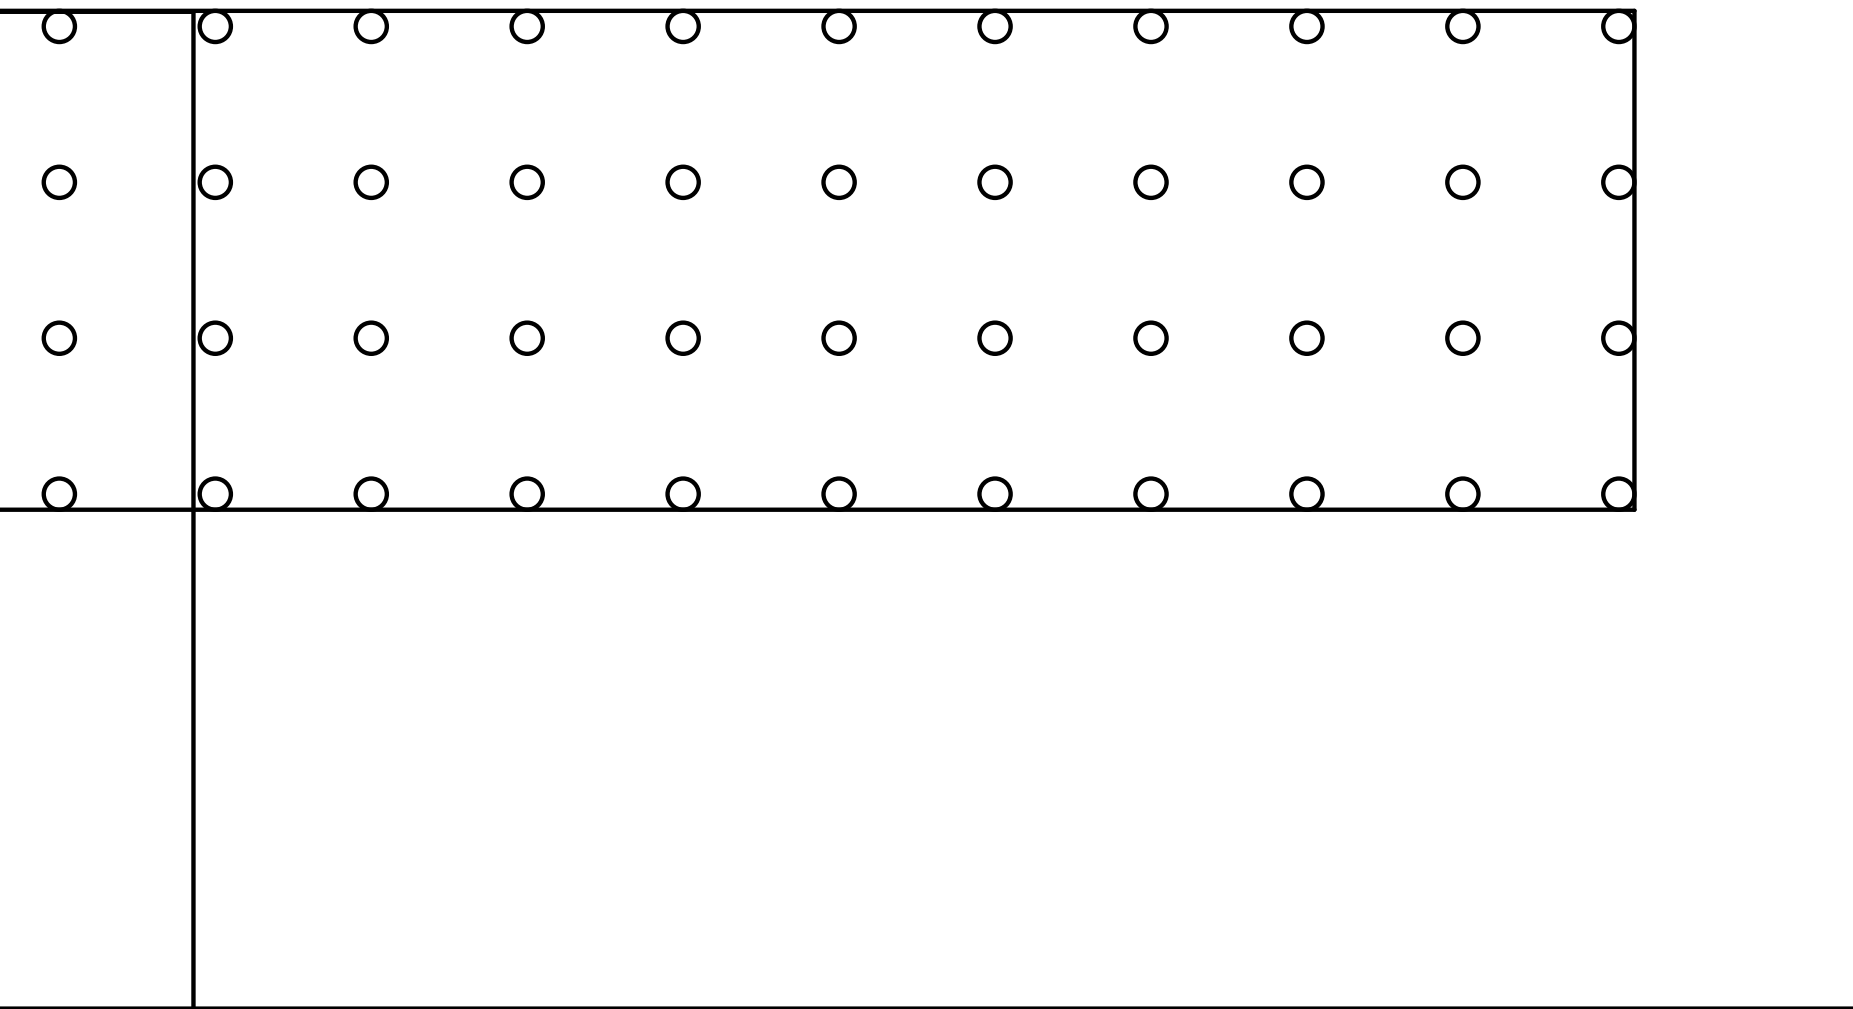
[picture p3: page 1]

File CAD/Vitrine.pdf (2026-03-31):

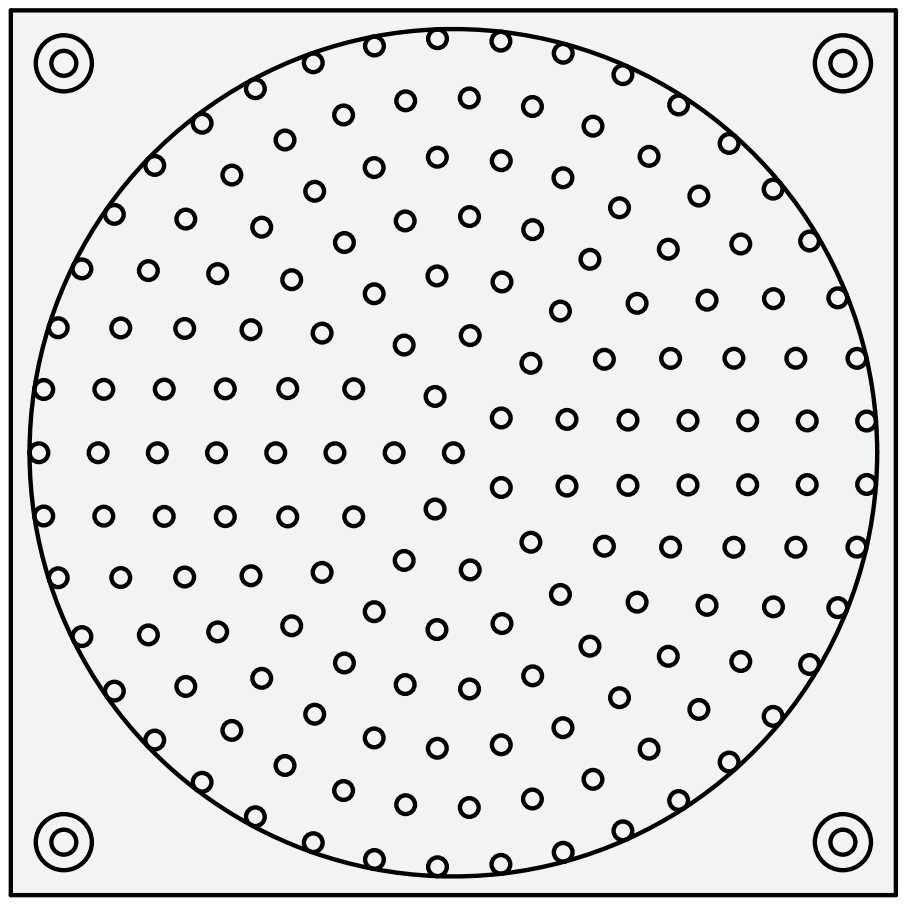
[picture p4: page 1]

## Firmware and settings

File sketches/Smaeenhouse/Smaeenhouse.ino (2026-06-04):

#include <Arduino.h>
#include <Wire.h>

#include "ClockService.h"
#include "Config.h"
#include "FanController.h"
#include "HAInterface.h"
#include "LightController.h"
#include "LightSensor.h"
#include "MoistureSensor.h"
#include "NetworkManager.h"
#include "PersistentConfig.h"
#include "SHTa.h"

namespace {

volatile bool shtAlertPending = false;
volatile bool rtcAlarmPending = false;

PersistentConfigManager configManager;
PersistentConfigData cfg{};

SHTa sht;
FanController fan;
ClockService clockService;
LightController light(configManager, cfg, clockService);
MoistureSensor moisture(PIN_SOIL_SENSOR);
LightSensor lightSensor;
NetworkManager networkManager;
HAInterface ha(fan, light, moisture, lightSensor, clockService, sht, configManager, cfg, networkManager);

bool fallbackWasActive = false;
bool lastKnownAutoMode = DEFAULT_LIGHT_AUTO_MODE;
bool lastKnownWifiConnected = false;
uint32_t lastShtStatusPollMs = 0;
bool hasFallbackResumeSnapshot = false;
LightResumeState fallbackResumeSnapshot{};

bool minuteIsInsideOnWindow(uint16_t minuteNow, uint16_t onMinute, uint16_t offMinute) {
  if (onMinute == offMinute) {
    return false;
  }

  if (onMinute < offMinute) {
    return minuteNow >= onMinute && minuteNow < offMinute;
  }

  return minuteNow >= onMinute || minuteNow < offMinute;
}

uint8_t currentAutoWindowTargetPercent() {
  if (!clockService.isTimeValid()) {
    return 0;
  }

  const uint16_t nowMinute = clockService.minutesSinceMidnight();
  const bool shouldBeOn =
      minuteIsInsideOnWindow(nowMinute, cfg.lightOnTimeMinutes, cfg.lightOffTimeMinutes);
  return shouldBeOn ? 100 : 0;
}

void alignLightWithCurrentAutoWindow() {
  if (!light.isAutoMode() || !clockService.isTimeValid()) {
    return;
  }

  light.startArduinoDimJob(currentAutoWindowTargetPercent(), 0);
}

void evaluateShtAlertsAndFanDemand() {
  if (sht.hasSensorReset()) {
    sht.applyThresholdConfig(cfg);
    sht.clearStatus();
  }

  const bool autoDemand = sht.hasHumAlert() || sht.hasTempAlert();
  fan.setAutoDemand(autoDemand);
}

void onShtAlertInterrupt() {
  shtAlertPending = true;
}

void onRtcAlarmInterrupt() {
  rtcAlarmPending = true;
}

}  // namespace

void setup() {
  Serial.begin(115200);

  Wire.begin();

  configManager.begin(Wire);
  cfg = configManager.current();
  Serial.print(F("PersistentConfig init: storageAvailable="));
  Serial.print(configManager.isStorageAvailable() ? F("YES") : F("NO"));
  Serial.print(F(", lightOnMinutes="));
  Serial.print(cfg.lightOnTimeMinutes);
  Serial.print(F(", lightOffMinutes="));
  Serial.print(cfg.lightOffTimeMinutes);
  Serial.print(F(", dimMinutes="));
  Serial.print(cfg.defaultLightDimMinutes);
  Serial.print(F(", fanAutoMode="));
  Serial.print(cfg.fanAutoMode ? F("ON") : F("OFF"));
  Serial.print(F(", lightAutoMode="));
  Serial.println(cfg.lightAutoMode ? F("ON") : F("OFF"));

  clockService.begin();
  const bool alarmsConfigured =
      clockService.configureScheduleAlarms(cfg.lightOnTimeMinutes, cfg.lightOffTimeMinutes);
  Serial.print(F("ClockService alarm config: success="));
  Serial.println(alarmsConfigured ? F("YES") : F("NO"));

  sht.begin();
  sht.startPeriodicMeasurement(REPEATABILITY_MEDIUM, MPS_ONE_PER_SECOND);
  sht.applyThresholdConfig(cfg);

  float initialTemperature = NAN;
  float initialHumidity = NAN;
  if (sht.readMeasurement(initialTemperature, initialHumidity)) {
    Serial.print(F("SHT init: temperature="));
    Serial.print(initialTemperature, 2);
    Serial.print(F(" C, humidity="));
    Serial.println(initialHumidity, 1);
  } else {
    Serial.println(F("SHT init: no initial measurement available."));
  }

  fan.begin();
  fan.setAutoMode(cfg.fanAutoMode);
  fan.setManualState(false);

  light.begin(Wire);
  light.setAutoMode(cfg.lightAutoMode);
  light.restoreOnBoot(cfg.lightAutoMode && clockService.isTimeValid(), currentAutoWindowTargetPercent());

  moisture.begin(cfg.soilAir, cfg.soilWater, cfg.soilDepthMm);
  lightSensor.begin(Wire);

  networkManager.begin();
  lastKnownWifiConnected = networkManager.isWifiConnected();
  ha.begin();

  if (clockService.syncFromNTP() && light.isAutoMode()) {
    alignLightWithCurrentAutoWindow();
  }

  pinMode(PIN_SHT_ALERT, INPUT_PULLUP);
  const int shtInterruptId = digitalPinToInterrupt(PIN_SHT_ALERT);
  if (shtInterruptId >= 0) {
    attachInterrupt(shtInterruptId, onShtAlertInterrupt, FALLING);
  } else {
    Serial.println(F("SHT alert pin does not support interrupts."));
  }

  pinMode(PIN_RTC_ALARM, INPUT_PULLUP);
  const int rtcInterruptId = digitalPinToInterrupt(PIN_RTC_ALARM);
  if (rtcInterruptId >= 0) {
    attachInterrupt(rtcInterruptId, onRtcAlarmInterrupt, FALLING);
  } else {
    Serial.println(F("RTC alarm pin does not support interrupts."));
  }

  shtAlertPending = true;
  lastKnownAutoMode = light.isAutoMode();
}

void loop() {
  const uint32_t nowMs = millis();

  networkManager.update(nowMs);
  const bool wifiConnectedNow = networkManager.isWifiConnected();
  if (wifiConnectedNow != lastKnownWifiConnected) {
    if (wifiConnectedNow) {
      Serial.println(F("Main loop detected WiFi connection."));
      if (!clockService.isTimeValid()) {
        clockService.syncFromNTP();
      }
    } else {
      Serial.println(F("Main loop detected WiFi disconnect."));
    }

    lastKnownWifiConnected = wifiConnectedNow;
  }

  clockService.update(nowMs);

  bool shouldDecodeShtStatus = false;
  if (shtAlertPending) {
    noInterrupts();
    shtAlertPending = false;
    interrupts();
    shouldDecodeShtStatus = true;
  }

  if (nowMs - lastShtStatusPollMs >= SHT_STATUS_POLL_INTERVAL_MS) {
    lastShtStatusPollMs = nowMs;
    shouldDecodeShtStatus = true;
  }

  if (shouldDecodeShtStatus && sht.decodeStatusRegister()) {
    evaluateShtAlertsAndFanDemand();
  }

  const bool autoModeNow = light.isAutoMode();
  if (autoModeNow != lastKnownAutoMode) {
    if (autoModeNow) {
      alignLightWithCurrentAutoWindow();
    }

    lastKnownAutoMode = autoModeNow;
  }

  if (rtcAlarmPending || clockService.hasPendingAlarmEvent()) {
    if (rtcAlarmPending) {
      noInterrupts();
      rtcAlarmPending = false;
      interrupts();
    }

    const ClockAlarmEvent alarmEvent = clockService.serviceAlarmFlags();
    if (light.isAutoMode()) {
      if (alarmEvent == ClockAlarmEvent::LightOnAlarm) {
        light.startArduinoDimJob(100, static_cast<uint32_t>(cfg.defaultLightDimMinutes) * 60000UL);
      } else if (alarmEvent == ClockAlarmEvent::LightOffAlarm) {
        light.startArduinoDimJob(0, static_cast<uint32_t>(cfg.defaultLightDimMinutes) * 60000UL);
      }
    }
  }

  const bool fallbackActive = networkManager.isFallbackActive();
  if (fallbackActive && !fallbackWasActive) {
    fallbackResumeSnapshot = cfg.lightResumeState;
    hasFallbackResumeSnapshot = true;

    if (cfg.lightFallbackMode == LIGHT_FALLBACK_USE_AUTO_MODE) {
      light.setAutoMode(true);
      alignLightWithCurrentAutoWindow();
    } else {
      light.applyHardPowerOff(true);
    }
  } else if (!fallbackActive && fallbackWasActive) {
    light.applyHardPowerOff(false);
    light.setAutoMode(cfg.lightAutoMode);

    if (!cfg.lightAutoMode && hasFallbackResumeSnapshot) {
      cfg.lightResumeState = fallbackResumeSnapshot;
      configManager.saveIfChanged(cfg);
      light.restoreOnBoot(false, 0);
    } else if (light.isAutoMode()) {
      alignLightWithCurrentAutoWindow();
    }

    hasFallbackResumeSnapshot = false;
  }
  fallbackWasActive = fallbackActive;

  fan.update(nowMs);
  light.update(nowMs);
  moisture.update(nowMs);
  lightSensor.update(nowMs);
  ha.update(nowMs);
}

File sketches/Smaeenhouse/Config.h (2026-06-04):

#pragma once

#include <Arduino.h>

// Pin mapping (Arduino Nano 33 IoT)
// Tach input is conditioned to 3.3V logic via documented 2N3904 stage.
constexpr uint8_t PIN_SHT_ALERT = 7;
constexpr uint8_t PIN_RTC_ALARM = 10;
constexpr uint8_t PIN_FAN_SWITCH = 2;
constexpr uint8_t PIN_FAN_TACH = A1;
constexpr uint8_t PIN_LIGHT_DIM_SHDN = 4;
constexpr uint8_t PIN_LIGHT_POWER = 3;
constexpr uint8_t PIN_SOIL_SENSOR = A0;
constexpr uint8_t PIN_LIGHT_SENSOR_INT = 9;

// Runtime timings
constexpr uint32_t SOIL_PUBLISH_INTERVAL_MS = 10000UL;
constexpr uint32_t TEMP_HUM_PUBLISH_INTERVAL_MS = 60000UL;
constexpr uint32_t FAN_RPM_PUBLISH_INTERVAL_MS = 30000UL;
constexpr uint32_t LIGHT_SENSOR_PUBLISH_INTERVAL_MS = 900000UL;  // 15 minutes
constexpr uint32_t SHT_STATUS_POLL_INTERVAL_MS = 5000UL;
constexpr uint32_t WIFI_RECONNECT_INTERVAL_MS = 10000UL;
constexpr uint32_t WIFI_DISCONNECT_SETTLE_MS = 1500UL;
constexpr uint32_t WIFI_CONNECT_TIMEOUT_MS = 15000UL;
constexpr uint8_t WIFI_CONNECT_ATTEMPTS = 2;
constexpr uint32_t MQTT_RECONNECT_INTERVAL_MS = 10000UL;
constexpr uint32_t NTP_RETRY_INTERVAL_MS = 60000UL;
constexpr uint32_t MQTT_FALLBACK_TIMEOUT_MS = 600000UL;  // 10 minutes
constexpr uint32_t NTP_RESYNC_INTERVAL_MS = 86400000UL;  // 24 hours
constexpr uint8_t HA_MQTT_ENTITY_LIMIT = 48;

// AD5263 dimmer hardware
constexpr uint8_t AD5263_I2C_ADDRESS = 0x2C;
constexpr bool AD5263_AD0_TO_GND = true;
constexpr bool AD5263_AD1_TO_GND = true;
constexpr uint8_t AD5263_CHANNEL_W1 = 0;
constexpr uint8_t AD5263_CHANNEL_W2 = 1;

constexpr uint8_t LIGHT_DIM_MAPPING_SPLIT_PERCENT = 50;

// Hardware-specific effective limits are still subject to bench validation.
constexpr uint8_t LIGHT_DIM_W2_RDAC_MIN_EFFECTIVE = 0;
constexpr uint8_t LIGHT_DIM_W2_RDAC_MAX_EFFECTIVE = 255;
constexpr uint8_t LIGHT_DIM_W1_RDAC_MIN_EFFECTIVE = 0;
constexpr uint8_t LIGHT_DIM_W1_RDAC_MAX_EFFECTIVE = 255;

constexpr uint8_t LIGHT_DIM_W2_AT_0_PERCENT = 0;
constexpr uint8_t LIGHT_DIM_W1_AT_0_PERCENT = 255;
constexpr uint8_t LIGHT_DIM_W2_AT_50_PERCENT = 0;
constexpr uint8_t LIGHT_DIM_W1_AT_50_PERCENT = 0;
constexpr uint8_t LIGHT_DIM_W2_AT_100_PERCENT = 255;
constexpr uint8_t LIGHT_DIM_W1_AT_100_PERCENT = 0;

constexpr uint8_t LIGHT_DIM_COMMAND_MAX_ATTEMPTS = 2;
constexpr uint16_t LIGHT_DIM_WRITE_SETTLE_MS = 2;
constexpr uint16_t LIGHT_DIM_BOOT_SETTLE_MS = 2;
constexpr uint32_t LIGHT_DIM_STEP_INTERVAL_MS = 100UL;
constexpr uint32_t FAN_FAULT_GRACE_MS = FAN_RPM_PUBLISH_INTERVAL_MS;
constexpr uint32_t LIGHT_RESUME_INVALID_EPOCH = 0UL;
constexpr uint8_t LIGHT_SENSOR_FAULT_FAILURE_COUNT = 3;

// CQrobot CQRTSL25911 / TSL25911 illuminance sensor
constexpr uint8_t TSL2591_I2C_ADDRESS = 0x29;

// WINGONEER Tiny DS3231 AT24C32 module
constexpr uint8_t RTC_EEPROM_I2C_ADDRESS = 0x57;
constexpr uint16_t RTC_EEPROM_PAGE_SIZE = 32;
constexpr uint16_t RTC_EEPROM_SIZE_BYTES = 4096;
constexpr uint32_t CONFIG_EEPROM_BASE_ADDRESS = 0;

// Persistent configuration defaults
constexpr uint16_t CONFIG_SCHEMA_VERSION = 3;

constexpr float DEFAULT_TEMP_HIGH_SET = 30.0f;
constexpr float DEFAULT_TEMP_HIGH_CLEAR = 28.0f;
constexpr float DEFAULT_TEMP_LOW_SET = 18.0f;
constexpr float DEFAULT_TEMP_LOW_CLEAR = 20.0f;

constexpr float DEFAULT_HUM_HIGH_SET = 85.0f;
constexpr float DEFAULT_HUM_HIGH_CLEAR = 80.0f;
constexpr float DEFAULT_HUM_LOW_SET = 35.0f;
constexpr float DEFAULT_HUM_LOW_CLEAR = 40.0f;

constexpr uint16_t DEFAULT_LIGHT_ON_TIME_MINUTES = 8 * 60;
constexpr uint16_t DEFAULT_LIGHT_OFF_TIME_MINUTES = 20 * 60;
constexpr uint16_t DEFAULT_LIGHT_DIM_MINUTES = 30;

constexpr bool DEFAULT_FAN_AUTO_MODE = true;
constexpr bool DEFAULT_LIGHT_AUTO_MODE = true;

constexpr int16_t SOIL_CAL_MIN = 0;
constexpr int16_t SOIL_CAL_MAX = 1000;
constexpr int16_t SOIL_DEPTH_MIN_MM = 0;
constexpr int16_t SOIL_DEPTH_MAX_MM = 120;
constexpr int16_t SOIL_REFERENCE_DEPTH_MM = 120;
constexpr int16_t SOIL_MIN_VALID_DEPTH_MM = 20;
constexpr int16_t SOIL_ADC_MIN = 0;
constexpr int16_t SOIL_ADC_MAX = 4095;

constexpr int16_t DEFAULT_SOIL_AIR = 1000;
constexpr int16_t DEFAULT_SOIL_WATER = 500;
constexpr int16_t DEFAULT_SOIL_DEPTH_MM = 50;

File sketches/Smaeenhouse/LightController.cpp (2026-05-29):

#include "LightController.h"

#include "Config.h"

namespace {

constexpr char kNoLightFault[] = "";
constexpr char kAd5263NotFound[] = "ad5263_not_found";
constexpr char kAd5263WriteFailed[] = "ad5263_write_failed";
constexpr char kAd5263ReadbackMismatch[] = "ad5263_readback_mismatch";

uint8_t clampPercentValue(uint8_t value) {
  return value > 100 ? 100 : value;
}

}  // namespace

LightController::LightController(PersistentConfigManager& configManager,
                                 PersistentConfigData& configData,
                                 ClockService& clockService)
    : configManager_(configManager),
      configData_(configData),
      clockService_(clockService) {
}

void LightController::begin(TwoWire& wire) {
  wire_ = &wire;

  pinMode(PIN_LIGHT_DIM_SHDN, OUTPUT);
  pinMode(PIN_LIGHT_POWER, OUTPUT);

  lightAutoMode_ = configData_.lightAutoMode;
  currentBrightnessPercent_ = 0;
  lastNonZeroBrightnessPercent_ = configData_.lightResumeState.lastNonZeroBrightnessPercent;
  if (lastNonZeroBrightnessPercent_ == 0 || lastNonZeroBrightnessPercent_ > 100) {
    lastNonZeroBrightnessPercent_ = 100;
  }

  hardPowerOffActive_ = false;
  lightFault_ = false;
  lightFaultReason_ = kNoLightFault;
  pendingFailureReason_ = kNoLightFault;
  activeDimJob_.active = false;
  shdnReleased_ = false;
  relayOn_ = false;
  initialized_ = true;

  setHardwareOutputs(false, false);

  Serial.print(F("LightController init: shdn pin "));
  Serial.print(PIN_LIGHT_DIM_SHDN);
  Serial.print(F("=LOW, relay pin "));
  Serial.print(PIN_LIGHT_POWER);
  Serial.println(F("=LOW"));
}

void LightController::restoreOnBoot(bool preferAutoScheduleState, uint8_t scheduleTargetPercent) {
  if (!initialized_) {
    return;
  }

  stopDimJob(false);

  const LightResumeState& resume = configData_.lightResumeState;
  lastNonZeroBrightnessPercent_ =
      (resume.lastNonZeroBrightnessPercent > 0 && resume.lastNonZeroBrightnessPercent <= 100)
          ? resume.lastNonZeroBrightnessPercent
          : 100;

  uint8_t targetPercent = clampPercent(resume.effectiveBrightnessPercent);
  hardPowerOffActive_ = (!lightAutoMode_ && resume.hardPowerOffActive != 0);

  if (lightAutoMode_ && preferAutoScheduleState) {
    targetPercent = clampPercent(scheduleTargetPercent);
    hardPowerOffActive_ = false;
  }

  if (!applyBrightnessInternal(targetPercent, true)) {
    return;
  }

  if (!lightAutoMode_ && !hardPowerOffActive_ && resume.haDimJobActive != 0 &&
      clockService_.isTimeValid() && resume.dimJobStartEpoch != LIGHT_RESUME_INVALID_EPOCH &&
      resume.dimJobDurationMs > 0) {
    const uint32_t nowEpoch = currentEpoch();
    const uint32_t elapsedSeconds = (nowEpoch > resume.dimJobStartEpoch)
                                        ? (nowEpoch - resume.dimJobStartEpoch)
                                        : 0;
    const uint64_t elapsedMs = static_cast<uint64_t>(elapsedSeconds) * 1000ULL;

    if (elapsedMs >= resume.dimJobDurationMs) {
      const uint8_t finalPercent = clampPercent(resume.dimJobTargetPercent);
      if (applyBrightnessInternal(finalPercent, true)) {
        persistResumeState(false, finalPercent, 0, 0, 0, LIGHT_RESUME_INVALID_EPOCH);
      }
      return;
    }

    const uint32_t remainingMs =
        resume.dimJobDurationMs - static_cast<uint32_t>(elapsedMs);
    const int16_t delta = static_cast<int16_t>(resume.dimJobTargetPercent) -
                          static_cast<int16_t>(resume.dimJobStartPercent);
    const float progress =
        static_cast<float>(elapsedMs) / static_cast<float>(resume.dimJobDurationMs);
    const int16_t interpolated =
        static_cast<int16_t>(resume.dimJobStartPercent + (delta * progress));
    const uint8_t resumedPercent =
        clampPercent(static_cast<uint8_t>(constrain(interpolated, 0, 100)));

    if (applyBrightnessInternal(resumedPercent, true)) {
      activeDimJob_.active = true;
      activeDimJob_.source = HA_CONTROL_SOURCE;
      activeDimJob_.startPercent = resumedPercent;
      activeDimJob_.targetPercent = clampPercent(resume.dimJobTargetPercent);
      activeDimJob_.startMs = millis();
      activeDimJob_.durationMs = remainingMs;
      activeDimJob_.lastStepMs = activeDimJob_.startMs;
    }

    return;
  }

  if (!lightAutoMode_ && resume.haDimJobActive != 0 && !clockService_.isTimeValid()) {
    persistResumeState(false,
                       currentBrightnessPercent_,
                       0,
                       0,
                       0,
                       LIGHT_RESUME_INVALID_EPOCH);
  }
}

void LightController::update(uint32_t nowMs) {
  if (!activeDimJob_.active || lightFault_) {
    return;
  }

  const uint32_t elapsed = nowMs - activeDimJob_.startMs;
  if (elapsed >= activeDimJob_.durationMs) {
    const uint8_t targetPercent = clampPercent(activeDimJob_.targetPercent);
    if (applyBrightnessInternal(targetPercent, true)) {
      persistResumeState(false,
                         targetPercent,
                         0,
                         0,
                         0,
                         LIGHT_RESUME_INVALID_EPOCH);
    }

    activeDimJob_.active = false;
    return;
  }

  if ((nowMs - activeDimJob_.lastStepMs) < LIGHT_DIM_STEP_INTERVAL_MS) {
    return;
  }

  activeDimJob_.lastStepMs = nowMs;

  const float progress = static_cast<float>(elapsed) / static_cast<float>(activeDimJob_.durationMs);
  const int16_t delta = static_cast<int16_t>(activeDimJob_.targetPercent) -
                        static_cast<int16_t>(activeDimJob_.startPercent);
  const int16_t interpolated =
      static_cast<int16_t>(activeDimJob_.startPercent + (delta * progress));
  const uint8_t stepPercent =
      clampPercent(static_cast<uint8_t>(constrain(interpolated, 0, 100)));

  if (stepPercent == currentBrightnessPercent_) {
    return;
  }

  if (!applyBrightnessInternal(stepPercent, false)) {
    activeDimJob_.active = false;
  }
}

void LightController::setAutoMode(bool enabled) {
  if (lightAutoMode_ == enabled) {
    return;
  }

  stopDimJob(true);
  lightAutoMode_ = enabled;

  if (lightAutoMode_) {
    hardPowerOffActive_ = false;
  }

  syncOutputsToState();
  persistResumeState(false,
                     currentBrightnessPercent_,
                     0,
                     0,
                     0,
                     LIGHT_RESUME_INVALID_EPOCH);
}

bool LightController::isAutoMode() const {
  return lightAutoMode_;
}

void LightController::applyManualBrightness(uint8_t percent) {
  stopDimJob(true);
  const uint8_t targetPercent = clampPercent(percent);
  if (applyBrightnessInternal(targetPercent, true)) {
    persistResumeState(false,
                       targetPercent,
                       0,
                       0,
                       0,
                       LIGHT_RESUME_INVALID_EPOCH);
  }
}
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

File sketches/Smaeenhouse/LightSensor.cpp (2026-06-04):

#include "LightSensor.h"

#include <math.h>

#include "Config.h"

LightSensor::LightSensor() : sensor_(2591) {
}

void LightSensor::begin(TwoWire& wire) {
  wire_ = &wire;
  pinMode(PIN_LIGHT_SENSOR_INT, INPUT_PULLUP);

  available_ = initializeSensor();
  fault_ = !available_;

  if (available_) {
    sampleNow();
  }

  lastReadMs_ = millis();

  Serial.print(F("LightSensor init: available="));
  Serial.print(available_ ? F("YES") : F("NO"));
  Serial.print(F(", intPin="));
  Serial.print(PIN_LIGHT_SENSOR_INT);
  if (lastSampleValid_) {
    Serial.print(F(", lux="));
    Serial.print(lastLux_, 1);
    Serial.print(F(", full="));
    Serial.print(lastFullSpectrum_);
    Serial.print(F(", ir="));
    Serial.print(lastInfrared_);
    Serial.print(F(", visible="));
    Serial.print(lastVisible_);
  }
  Serial.println();
}

void LightSensor::update(uint32_t nowMs) {
  if (nowMs - lastReadMs_ < LIGHT_SENSOR_PUBLISH_INTERVAL_MS) {
    return;
  }

  sampleNow();
  lastReadMs_ = nowMs;
}

void LightSensor::sampleNow() {
  if (wire_ == nullptr) {
    markReadFailure();
    return;
  }

  if (!available_ && !initializeSensor()) {
    markReadFailure();
    return;
  }

  const uint32_t luminosity = sensor_.getFullLuminosity();
  const uint16_t infrared = static_cast<uint16_t>(luminosity >> 16);
  const uint16_t fullSpectrum = static_cast<uint16_t>(luminosity & 0xFFFF);
  const float lux = sensor_.calculateLux(fullSpectrum, infrared);

  if (isnan(lux) || isinf(lux) || lux < 0.0f) {
    markReadFailure();
    return;
  }

  lastInfrared_ = infrared;
  lastFullSpectrum_ = fullSpectrum;
  lastVisible_ = (fullSpectrum >= infrared) ? (fullSpectrum - infrared) : 0;
  lastLux_ = lux;
  lastSampleValid_ = true;
  consecutiveReadFailures_ = 0;
  available_ = true;
  fault_ = false;
}

bool LightSensor::isAvailable() const {
  return available_;
}

bool LightSensor::hasFault() const {
  return fault_;
}

bool LightSensor::hasValidSample() const {
  return lastSampleValid_;
}

float LightSensor::getLastLux() const {
  return lastLux_;
}

uint16_t LightSensor::getLastFullSpectrum() const {
  return lastFullSpectrum_;
}

uint16_t LightSensor::getLastInfrared() const {
  return lastInfrared_;
}

uint16_t LightSensor::getLastVisible() const {
  return lastVisible_;
}

bool LightSensor::initializeSensor() {
  if (wire_ == nullptr) {
    return false;
  }

  if (!sensor_.begin(wire_, TSL2591_I2C_ADDRESS)) {
    available_ = false;
    return false;
  }

  sensor_.setGain(TSL2591_GAIN_LOW);
  sensor_.setTiming(TSL2591_INTEGRATIONTIME_100MS);
  sensor_.clearInterrupt();

  available_ = true;
  return true;
}

void LightSensor::markReadFailure() {
  lastSampleValid_ = false;
  available_ = false;

  if (consecutiveReadFailures_ < 255) {
    consecutiveReadFailures_++;
  }

  if (consecutiveReadFailures_ >= LIGHT_SENSOR_FAULT_FAILURE_COUNT) {
    fault_ = true;
  }
}

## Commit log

2026-03-06 Initial Commit
    Heavily helped (destroyed) by ChatGPT, many modules not ready, too interconnected to the HA Interface that is not there at all
    [FullArduinoHouse.fzz]
2026-03-31 Hardware changes, new code and more documentation
    Needed to change some hardware and also used Codex to complete the code after generating detailed documentation and specs.
    Also there are some freeCAD drawings and a frizzing file now
    [FullArduinoHouse.fzz, Vitrine.FCStd]
2026-04-05 fix Wifi and MQTT
    fixed wifi connection process and MQTT topic management
    [ClockService.cpp, FanController.cpp, HAInterface.cpp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]
2026-04-06 Updated branch documentation in preparation of hardware change
    The optocoupler approach failed, so I'm trying out a digital potentiometer, the AD5263 in 50kohm/3.3V variant
2026-05-13 Document soil calibration depth correction model
2026-05-15 Invert AD5263 dimmer mapping in docs
    [FullArduinoHouse.fzz]
2026-05-16 Fix AD5263 mapping and soil depth calibration
    [AD5263Test.ino, Config.h, HAInterface.cpp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]
2026-05-29 docs: split roadmap and decisions from main docs
    [FullArduinoHouse.fzz]
2026-05-29 chore: migrate Arduino project to template layout
2026-05-31 feat: add cabinet light sensor
    [FullArduinoHouse.fzz]
2026-06-02 test: add CQRTSL25911 sensor sketch
2026-06-02 docs: move light sensor test notes
2026-06-02 chore: reduce light sensor sample rate
2026-06-04 Fix HA entity registration and fault reason publishing
    [Config.h, HAInterface.cpp, HAInterface.h]
